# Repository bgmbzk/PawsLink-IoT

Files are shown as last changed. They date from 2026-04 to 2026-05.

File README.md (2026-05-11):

# 🐾 PawsLink IoT: The Elite Cat Gate Controller

Selam! Bu proje, evin asıl sahibi olan kedimin balkon kapısında mahsur kalma krizlerine (ve benim her seferinde bir "kapı görevlisi" edasıyla yerimden kalkmama) son vermek için geliştirildi. Başta küçük bir can sıkıntısı gibi görünse de, süreç içinde evrim geçirerek tam kapsamlı bir **Embedded System & IoT** projesine dönüştü.

## 📸 Tasarım Süreci ve Görseller

### 🎨 Şematik Tasarım
Projenin elektriksel bağlantıları ve ESP32 entegrasyonu:
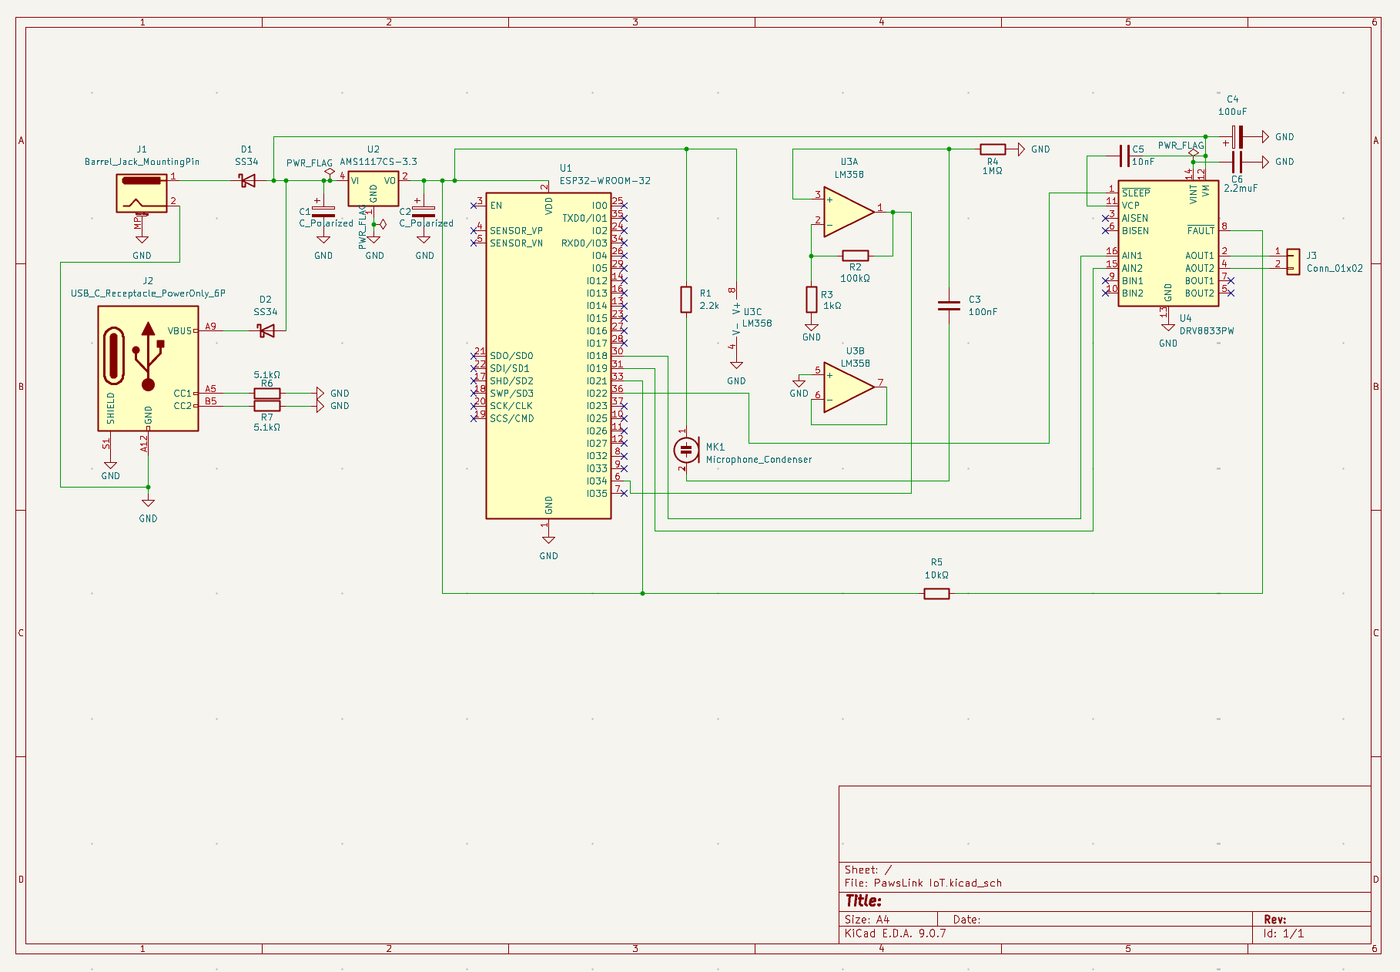
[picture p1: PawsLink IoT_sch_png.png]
Schematic Design


---

### 🛣️ PCB Layout
Hassas sinyal yolları ve RF performansını korumak için tasarlanan Anten Keep-out bölgesi:
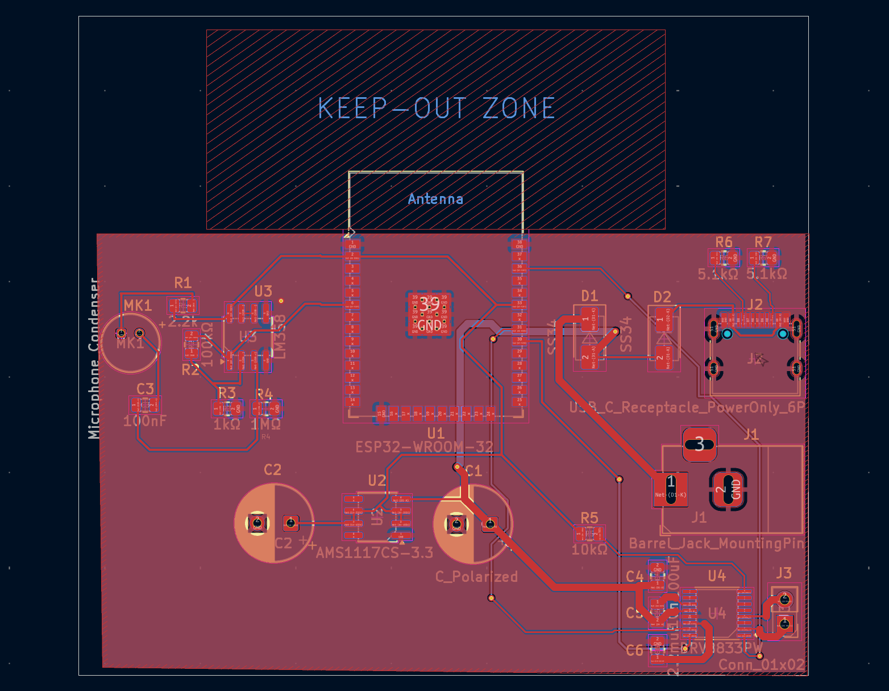
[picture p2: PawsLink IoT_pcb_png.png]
PCB Layout


---

### 🧊 3D Modelleme
Üretim sonrası kartın fiziksel görünümü ve komponent yerleşimi:
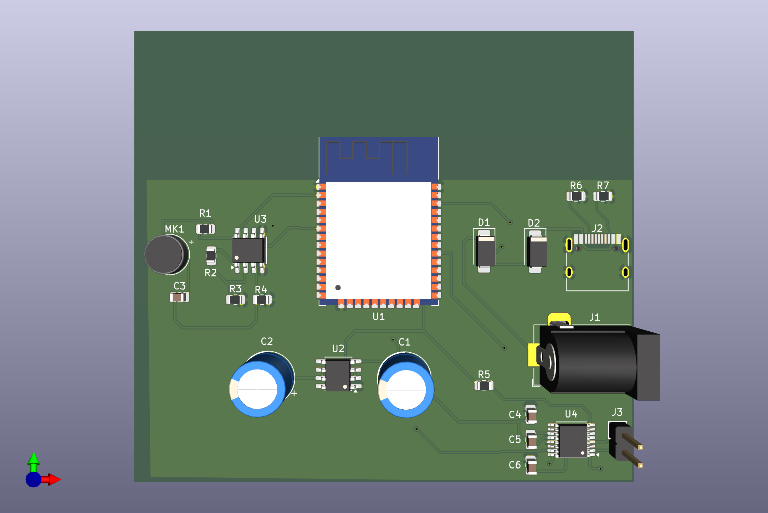
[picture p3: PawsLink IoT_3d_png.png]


## 🐱 Neden PawsLink?
Kedim, balkona çıkmak istediğinde kapının önünde kendine has bir frekansta seslenerek beni göreve çağırıyor. **PawsLink**, bu işitsel sinyalleri (miyavlamaları) algılayıp mekanik bir kolu tetikleyen, böylece kedime kendi özgürlüğünü sunan akıllı bir sistemdir.

## 🛠 Teknik Gelişim & Mühendislik Detayları
Proje başlangıçta **ATmega** tabanlıydı; ancak hem performansını artırmak hem de modern bağlantı özelliklerinden (Wi-Fi/Bluetooth) faydalanmak amacıyla mimariyi **ESP32**’ye taşıdım. Tasarımda dikkat ettiğim bazı kritik teknik noktalar:

* **RF Performansı (Anten Keep-out):** ESP32'nin üzerindeki PCB antenin verimli çalışması için, antenin altında kalan tüm katmanlarda bakır dökümü iptal edildi (No-copper zone).
* **Hassas PCB Layout:** USB-C güç girişi gibi yüksek yoğunluklu pinlerde kısa devre riskini önlemek için özel clearance (güvenlik mesafesi) ayarları yapıldı.
* **EMI ve Gürültü Yönetimi:** Güç hatları üzerine yerleştirilen decoupling kapasitörleri ile dijital gürültü minimize edildi, analog ses sensörünün daha kararlı çalışması sağlandı.
* **Hatasız Tasarım:** Endüstriyel standartlarda, **0 DRC Error** ve **0 Unconnected Items** ile üretime hazır hale getirildi.

 ---

# 🛠 Donanım Güncellemesi: V1.1 - Güç Optimizasyonu

Sistem kararlılığını ve motor performansını artırmak için yapılan iyileştirmeler:

* **Yol Kalınlaştırma (Power Tracks):** Motoru besleyen ana hatlar ve motor çıkış yolları **40 mil (~1.0 mm)** genişliğine çıkarıldı. Bu sayede motorun çektiği anlık akım, kartta ısınmaya veya voltaj düşümüne sebep olmadan güvenle iletilebiliyor.
* **Güç Otobanı:** Barrel Jack girişinden başlayarak Diyot, Kapasitörler ve Motor Sürücüye (DRV8833) giden hat "Güç Otobanı" mantığıyla optimize edildi. Bu güncelleme, motor zorlandığında bile ESP32'nin stabil çalışmasını (brown-out önleme) sağlar.
* **GND Plane:** Toprak hattı kesintisiz bakır döküm (GND Plane) olarak tasarlanarak hem parazitler engellendi hem de termal yönetim iyileştirildi.

---

## 📂 Dosya Yapısı
* `/Hardware`: KiCad şematik ve PCB layout dosyaları.
* `/Production`: Üretime hazır Gerber ve Drill dosyaları (PawsLink_Final_v1.zip).
* `/Firmware`: ESP32 için yazılmış IoT kontrol kodları.

---

### 🚀 Nasıl Çalışır?
1. PCB sipariş edilir ve bileşenler lehimlenir.
2. ESP32 yazılımı yüklenir.
3. Kedinin "miyav" frekansı kalibre edilir.
4. Koltuğa yaslanılır ve kedinin kendi kapısını açışı izlenir. ✨

---

## 🚀 Son Güncellemeler (Mayıs 2026)

Bu donanım revizyonu, güvenlik önlemlerine odaklanmakta ve sistemi akıllı yazılım entegrasyonuna hazırlamaktadır. Proje, kapı hareketi sırasında kedi güvenliğini sağlamak için proaktif önlemler içerecek şekilde geliştirilmiştir.

### Donanım v1.2 İyileştirmeleri
*   **Akıllı Engel Algılama**: HuskyLens entegrasyonu için özel bir 4-pinli konnektör (**J4**) eklendi. Bu sayede, mekanizma çalışmadan önce yapay zeka destekli algılama ile kedinin kapı eşiğinde olup olmadığı kontrol edilebilecektir.
*   **Görsel Durum LED'i**: Sistem durumunu ve olası engelleri gerçek zamanlı olarak bildirmek için yeni bir gösterge LED'i eklendi.
*   **Güç Kararlılığı**: ESP32 ve motor sürücüsünün yük altında kararlı çalışması için PCB yolları, net atamaları (USB-C pin eşleme düzeltmeleri dahil) ve bakır alanlar optimize edildi.
*   **Üretime Hazır Düzen**: Fiziksel PCB üretimine hazırlık amacıyla tasarım kuralı hataları (DRC) ve açıklık (clearance) ihlalleri giderildi.

### Güncel Proje Görselleri

#### Yeni Şematik Tasarımı
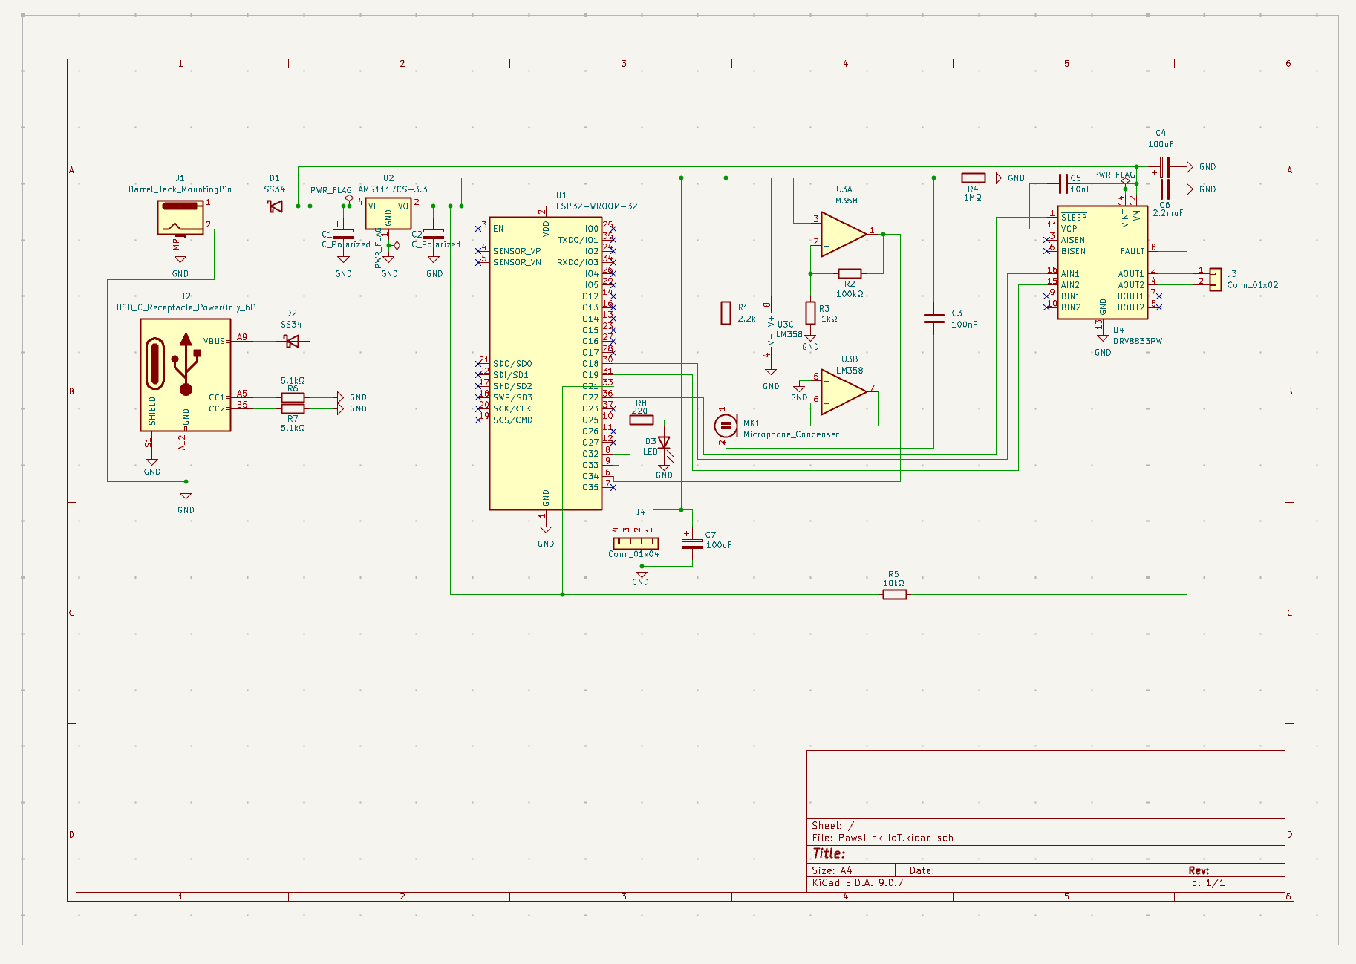
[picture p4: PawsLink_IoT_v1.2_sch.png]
Şematik


#### Yeni PCB Tasarımı
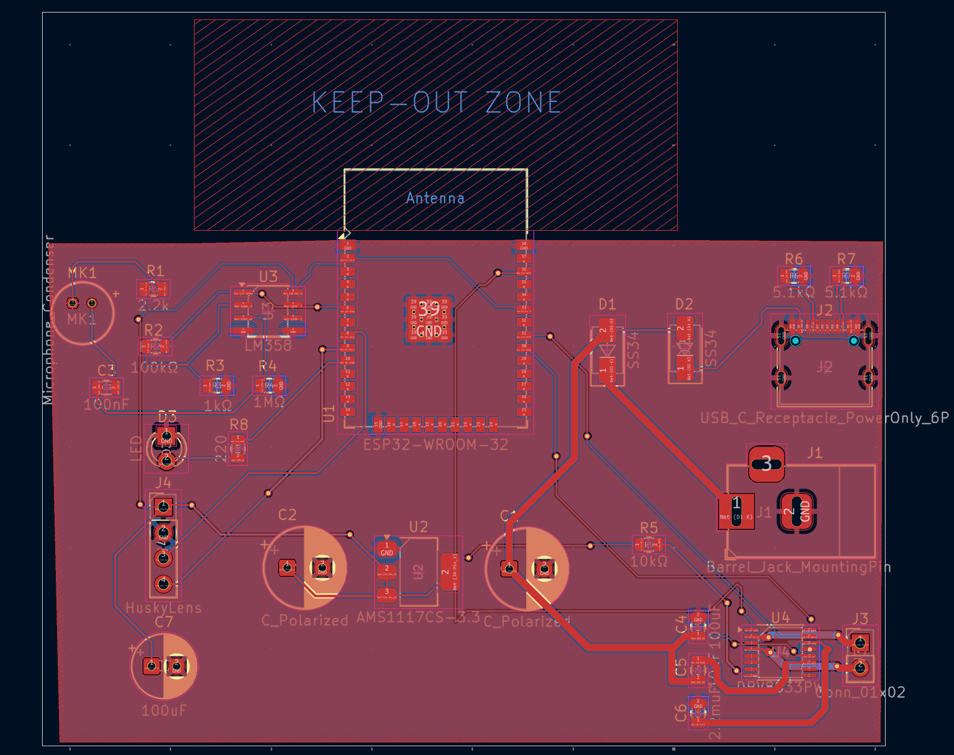
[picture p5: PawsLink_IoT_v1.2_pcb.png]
PCB


#### 3D Donanım Modeli
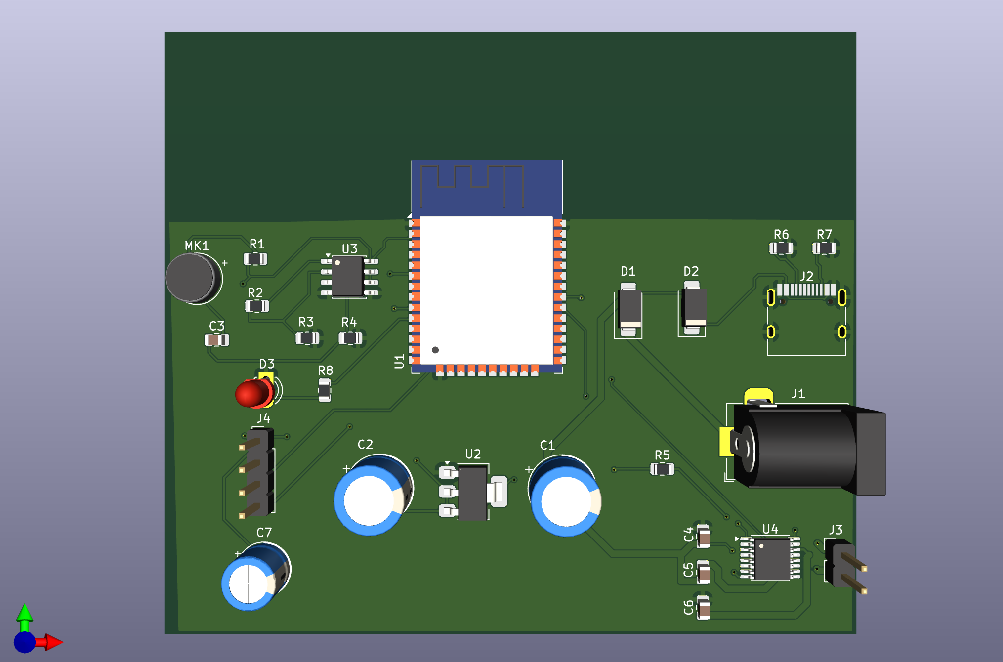
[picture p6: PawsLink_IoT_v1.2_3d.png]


## 💻 Yazılım Özellikleri (Firmware)

Projenin yazılımı ESP32 üzerinde C++ (Arduino) kullanılarak geliştirilmiştir. Temel çalışma mantığı şu şekildedir:

* **Tetikleme:** LM358 amfi devresi üzerinden gelen analog ses verisiyle kedinin miyavlaması algılanır.
* **Güvenlik:** HuskyLens AI kamera, I2C üzerinden ESP32 ile haberleşerek kedinin kapı eşiğinde olup olmadığını denetler.
* **Akıllı Döngü:** Kapı sadece miyavlama duyulduğunda açılır ve kedi eşikten tamamen ayrıldığında (HuskyLens onayıyla) güvenli bir şekilde kapanır.
* **Enerji Tasarrufu:** DRV8833 motor sürücüsü, işlem yapılmadığı anlarda `SLEEP` moduna alınarak güç tüketimi minimize edilir.
---

*Not: Bu donanım versiyonu ile eşzamanlı geliştirilen ESP32 yazılımı güncellenmelere açıktır. *

**Not2:** Bu proje yapılırken hiçbir kedi mahsur bırakılmamıştır. Aksine, artık evin kapıları onun kontrolü altında! 🐈‍⬛🚀

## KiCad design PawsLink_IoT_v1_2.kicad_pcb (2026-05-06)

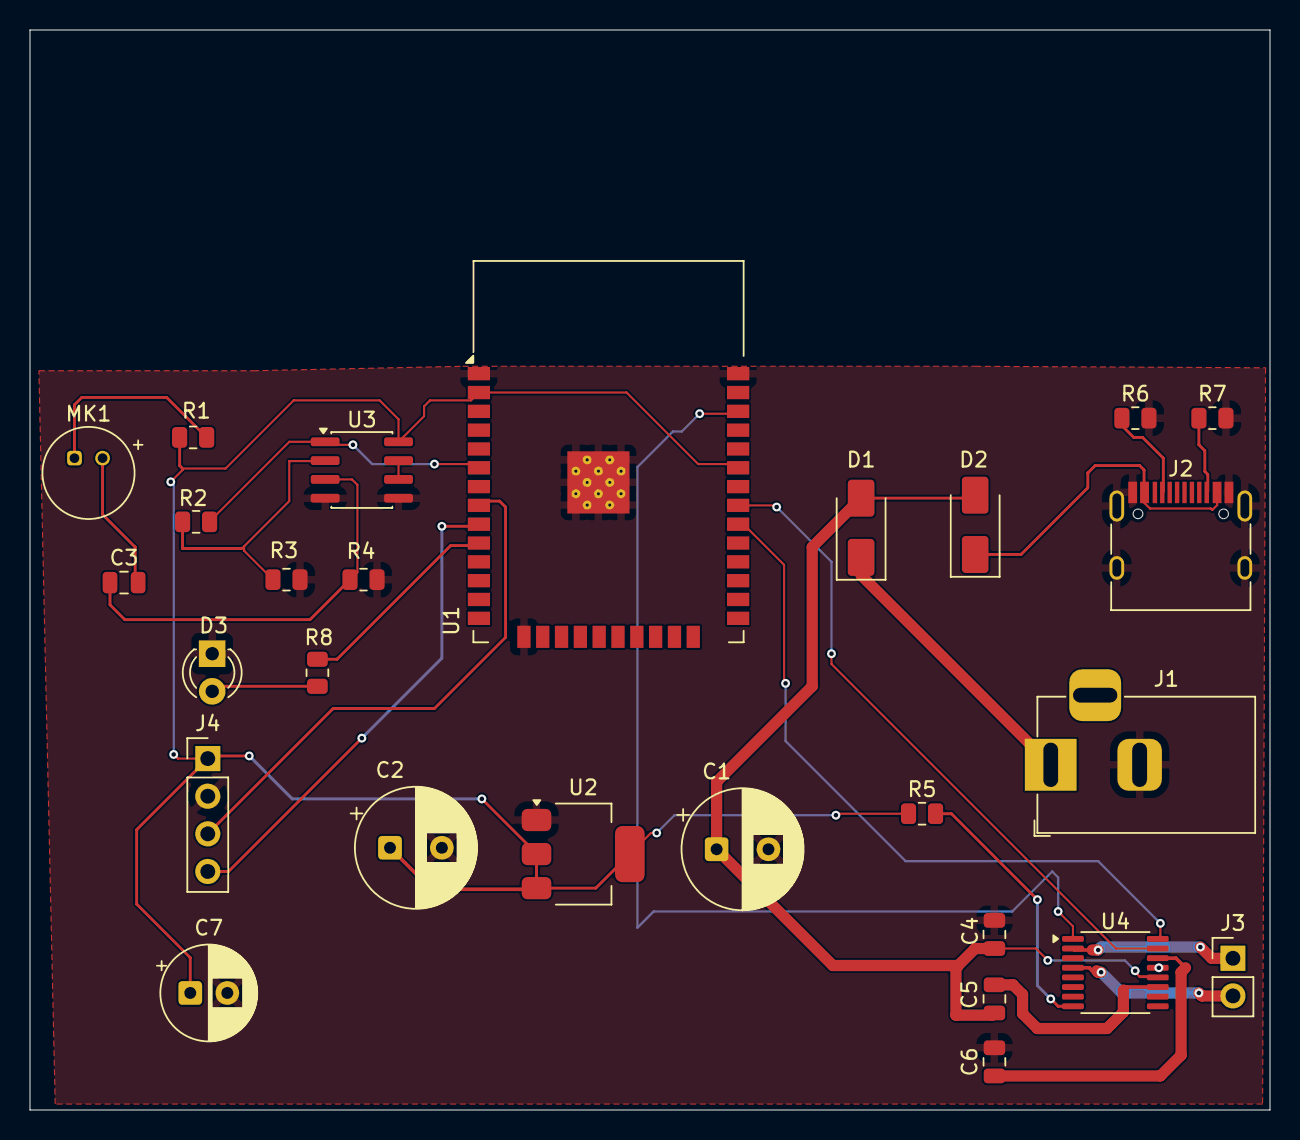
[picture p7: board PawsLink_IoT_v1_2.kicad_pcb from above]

Board: 2 copper layers, 83.7 x 72.9 mm, 27 parts (0 on the bottom side), 25 nets.

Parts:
C1, C2: C_Polarized; CP_Radial_D8.0mm_P3.50mm
C3: 100nF; C_0805_2012Metric
C4: 100uF; C_0805_2012Metric
C5: 10nF; C_0805_2012Metric
C6: 2.2muF; C_0805_2012Metric
C7: 100uF; CP_Radial_D6.3mm_P2.50mm
D1, D2: SS34; D_SMA
D3: LED; LED_D3.0mm
J1: Barrel_Jack_MountingPin; BarrelJack_Horizontal
J2: USB_C_Receptacle_PowerOnly_6P; USB_C_Receptacle_HRO_TYPE-C-31-M-12
J3: Conn_01x02; PinHeader_1x02_P2.54mm_Vertical
J4: Conn_01x04; PinHeader_1x04_P2.54mm_Vertical
MK1: Microphone_Condenser; POM-2244P-C3310-2-R
R1: 2.2k; R_0805_2012Metric
R2: 100kΩ; R_0805_2012Metric
R3: 1kΩ; R_0805_2012Metric
R4: 1MΩ; R_0805_2012Metric
R5: 10kΩ; R_0805_2012Metric
R6, R7: 5.1kΩ; R_0805_2012Metric
R8: 220; R_0805_2012Metric
U1: ESP32-WROOM-32
U2: AMS1117CS-3.3; SOT-223-3_TabPin2
U3: LM358; SOIC-8_3.9x4.9mm_P1.27mm
U4: DRV8833PW; TSSOP-16_4.4x5mm_P0.65mm

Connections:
GND: C1.2, C2.2, C4.2, C6.2, C7.2, D3.1 (K), J1.2, J2.A1, J2.A12 (GND), J2.B1, J2.B12 (GND), J2.S1 (SHIELD), J4.2, R3.2, R4.2, R6.2, R7.2, U1.1 (GND), U1.15 (GND), U1.38 (GND), U1.39 (GND), U2.1 (GND), U3.4 (V-), U3.5 (+), U4.13 (GND)
unnamed: C1.1, C4.1, C5.2, D1.2 (A), D2.2 (A), U4.12 (VM)
unnamed: D1.1 (K), J1.1
unnamed: D2.1 (K), J2.A4, J2.A9 (VBUS), J2.B4, J2.B9 (VBUS)
unnamed: D3.2 (A), R8.2
unnamed: J2.A5 (CC1), R6.1
unnamed: J2.B5 (CC2), R7.1
unnamed: J3.1, U4.2 (AOUT1)
unnamed: J3.2, U4.4 (AOUT2)
unnamed: C2.1, C7.1, J4.1, R1.1, R5.1, U1.2 (VDD), U1.33 (IO21), U2.2 (VO), U2.3 (VO), U3.8 (V+)
unnamed: J4.3, U1.8 (IO32)
unnamed: J4.4, U1.9 (IO33)
unnamed: C3.2, MK1.2 (+)
unnamed: MK1.1 (-), R1.2
unnamed: U1.30 (IO18), U4.16 (AIN1)
unnamed: U1.31 (IO19), U4.15 (AIN2)
unnamed: U1.36 (IO22), U4.1 (~SLEEP)
unnamed: R8.1, U1.10 (IO25)
unnamed: R2.2, U1.6 (IO34), U3.1
unnamed: C3.1, R4.1, U3.3 (+)
unnamed: R2.1, R3.1, U3.2 (-)
unnamed: U3.6 (-), U3.7
unnamed: C5.1, U4.11 (VCP)
unnamed: C6.1, U4.14 (VINT)
unnamed: R5.2, U4.8 (~FAULT)

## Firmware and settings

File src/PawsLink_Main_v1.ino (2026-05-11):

#include "HUSKYLENS.h"
#include "Wire.h"

// --- Esp32'nin Pin Tanımlamaları ---
#define MIC_PIN 34      
#define LED_PIN 25      
#define SDA_PIN 32      
#define SCL_PIN 33      
#define MOTOR_AIN1 18
#define MOTOR_AIN2 19
#define MOTOR_SLEEP 22

const int MIYAV_THRESHOLD = 2000; 
bool kapiAcik mi = false; // Kapının durumunu takip etmek için

HUSKYLENS huskylens;

void setup() {
    Serial.begin(115200);
    Wire.begin(SDA_PIN, SCL_PIN);
    
    pinMode(MIC_PIN, INPUT);
    pinMode(LED_PIN, OUTPUT);
    pinMode(MOTOR_AIN1, OUTPUT);
    pinMode(MOTOR_AIN2, OUTPUT);
    pinMode(MOTOR_SLEEP, OUTPUT);

    kapiyiKilitle(); // Başlangıçta motoru kapat ve uykula
    
    while (!huskylens.begin(Wire)) {
        Serial.println("HuskyLens bekleniyor...");
        delay(1000);
    }
}

// --- Motor Fonksiyonları (Kodun okunabilirliği için) ---
void kapiyiAc() {
    digitalWrite(MOTOR_SLEEP, HIGH);
    digitalWrite(MOTOR_AIN1, HIGH);
    digitalWrite(MOTOR_AIN2, LOW);
    delay(2000); // Kapının tamamen açılması için gereken süre (Ayarlanabilir)
    motoruDurdur();
}

void kapiyiKapat() {
    digitalWrite(MOTOR_SLEEP, HIGH);
    digitalWrite(MOTOR_AIN1, LOW);
    digitalWrite(MOTOR_AIN2, HIGH);
    delay(2000); // Kapının tamamen kapanması için gereken süre
    kapiyiKilitle();
}

void motoruDurdur() {
    digitalWrite(MOTOR_AIN1, LOW);
    digitalWrite(MOTOR_AIN2, LOW);
}

void kapiyiKilitle() {
    motoruDurdur();
    digitalWrite(MOTOR_SLEEP, LOW);
}

void loop() {
    // 1. Sensör Verileri
    int sesSeviyesi = analogRead(MIC_PIN);
    bool kediEsikte = false;

    if (huskylens.request()) {
        while (huskylens.available()) {
            HUSKYLENS_Result result = huskylens.read();
            if (result.ID == 1) kediEsikte = true;
        }
    }

    // 2. Senaryo Yönetimi
    if (!kapiAcikmi) {
        // KAPI KAPALI: Miyavlama bekliyoruz
        if (sesSeviyesi > MIYAV_THRESHOLD) {
            Serial.println("Miyav algılandı! Kapı açılıyor...");
            kapiyiAc();
            kapiAcikmi = true;
        }
    } 
    else {
        // KAPI AÇIK: Kedinin geçmesini ve eşikten ayrılmasını bekliyoruz
        digitalWrite(LED_PIN, kediEsikte ? HIGH : LOW); // Kedi eşikteyse LED yansın

        if (kediEsikte) {
            Serial.println("Kedi hala eşikte, kapanma bekletiliyor...");
            // Kedi eşikteyken hiçbir şey yapma, bekle.
        } 
        else {
            // Eşik boşaldı! 3 saniye daha bekle (garanti olsun) ve kapat
            Serial.println("Eşik boş. 3 saniye sonra kapanıyor...");
            delay(3000); 
            kapiyiKapat();
            kapiAcikmi = false;
        }
    }

    delay(100);
}

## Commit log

2026-04-29 Add hardware update V1.1 for power optimization
    Refactor: Widen power traces to 40mils for increased current capacity and system stability
2026-05-06 v1.2 Update: STM32 Shift & PCB Design
    ESP32 Hardware Update: Refined the existing ESP32-based design for better stability and future firmware development.
    Safety Features: Added a dedicated LED and HuskyLens connector (J4) to detect if the cat is standing in the doorway, preventing accidental closure.
    PCB Refinement: Optimized power routing and component placement to ensure reliable sensor data for the upcoming coding phase.
    Ready for Firmware: Hardware is now fully prepared for the next step: writing the ESP32 logic for cat-detection and automated door control.
    [PawsLink_IoT_v1_2.kicad_pcb, PawsLink_IoT_v1_2.kicad_sch]
2026-05-11 Create PawsLink_Main_v1.ino
    Add: Initial ESP32 firmware for cat detection and motor control
2026-05-11 Add Yazılım Özellikleri section to README
    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
2026-05-11 Revise note on ESP32 software updates
    Updated note regarding ESP32 software development readiness.
